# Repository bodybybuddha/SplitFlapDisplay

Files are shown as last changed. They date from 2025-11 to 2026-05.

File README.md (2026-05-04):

# Split-Flap Display

A modular, 3D-printed split-flap display controllable over RS485 from a Raspberry Pi. Each module holds 64 characters and modules can be chained together to build a display of any width.

**YouTube Build Video:** https://www.youtube.com/watch?v=-C8_AtxEEQc

---

## How It Works

Each module contains:
- A 3D-printed drum that holds 64 individual flaps (one per character)
- A stepper motor driving the drum through a gear train
- A Hall effect sensor for homing
- A custom driver PCB (ATtiny1616 + RS485 transceiver + ULN2003 stepper driver)

Modules communicate over a shared RS485 bus. A Raspberry Pi running a Python web interface sends commands over USB-RS485 to each module individually by address.

---

## Repository Structure

```
CAD/                              - 3D printable parts (Bambu Lab profiles included)
FlapsGenerator/                   - OpenSCAD code to automatically generate (custom) flaps
SplitFlapDriverATtiny1616 V2 KiCad/  - Driver PCB KiCad that I used in the video, for my build
SplitFlapDriverATtiny1616V3       - Updated Driver PCB KiCad project, which should be slightly cheaper to manufacture
SplitFlapBusBoard KiCad/          - Bus board KiCad project
SplitFlapFirmware/                - Arduino firmware for the PCBs
SplitFlap-RPI-FRONTEND/           - Raspberry Pi Python web frontend
Reference Docs/                   - Component datasheets
BOM.md                            - Bill of materials

**OnShape Model:** https://cad.onshape.com/documents/87c916b33ca5d6492b457485/w/b3e5f0f05f6619e6e7931347/e/582ef2164e20b0aa994708ab
```

---

## Parts List

See [BOM.md](BOM.md) for the complete bill of materials, broken into three sections:

- **PCB / Electronics** — all SMD components with JLCPCB part numbers for easy ordering
- **Module BOM** — 3D printed parts and hardware per module, with quantities scaled to 45 modules
- **Other Components** — system-level parts (Raspberry Pi, power supply, C14 connector, etc.)

---

## Ordering the PCB from JLCPCB

The driver board is designed to be ordered from JLCPCB with their PCB Assembly (PCBA) service so the SMD components arrive pre-soldered.

### Step 1 — Export Gerbers from KiCad

1. Open the project in `SplitFlapDriverATtiny1616 V2 KiCad/`
2. In KiCad PCB editor, go to **File → Fabrication Outputs → Gerbers**
3. Export to a folder, then zip the contents
4. Also export the drill file from the same menu

Alternatively, pre-exported Gerber and PCBA files are already be present in the KiCad project folder.

### Step 2 — Upload to JLCPCB

1. Go to [jlcpcb.com](https://jlcpcb.com) and click **Order Now**
2. Upload the Gerber zip file
3. Set your desired quantity (minimum 5)
4. Leave most settings at default; adjust PCB colour if desired

### Step 3 — Enable PCB Assembly (PCBA)

1. Toggle **PCB Assembly** on
2. Select **Standard PCBA** and set the assembly side to **Top Side**
3. Click **Confirm**

### Step 4 — Upload BOM and CPL Files

1. Upload the **BOM file** from the KiCad project folder — this maps component values to JLCPCB part numbers. The part numbers in `BOM.md` match what is in this file.
2. Upload the **CPL (Component Placement List)** file — this tells JLCPCB where each component sits on the board
3. Review the component matches on the next screen. All parts should auto-match using the C-numbers in [BOM.md](BOM.md). Confirm any that need manual review.

### Step 5 — Review and Order

1. Check the parts list — confirm quantities and part numbers match the [BOM.md](BOM.md) PCB section
2. Proceed through the review screens and place your order

> **Note:** A few through-hole parts (pin headers, JST connectors) are not included in PCBA. These are listed in the BOM and will need to be soldered by hand.

---

## 3D Printing

All printable files are in the `CAD/` folder. A Bambu Lab print profile is included in `CAD/64FlapsWithLetters/` for the flaps. Print the flaps in the correct colour for each character — see the video for details on the full 64-character set.

Parts per module:
- Enclosure Body, Right Cover, Left Cover
- Drum Body, Drum Cap
- Motor Gear, Center Gear, Gear Plate
- DIN Rail Mount, Wire Retainer
- 64 Flaps

### Creating your own flaps

If you want to generate your own flaps, with your own font, size and characters, you can use the OpenSCAD script to automatically generate this.

---

## Firmware

Located in `SplitFlapFirmware/`. The firmware is Arduino-based and targets the ATtiny1616.

- Flash via UPDI programmer (see https://github.com/SpenceKonde/AVR-Guidance/blob/master/UPDI/jtag2updi.md if you need to make one)
- Each module needs a unique address (0–44) stored in EEPROM. Be sure to edit this between flashes.

---

## Frontend

Located in `SplitFlap-RPI-FRONTEND/`. A Python web interface running on a Raspberry Pi sends display commands over USB-RS485 at 115200 baud.

Need a USB-serial dongle. I used this one: https://www.adafruit.com/product/5994

---

## License

This project is licensed under [Creative Commons Attribution-NonCommercial-ShareAlike 4.0 International (CC BY-NC-SA 4.0)](https://creativecommons.org/licenses/by-nc-sa/4.0/).

You are free to share and adapt this project for non-commercial purposes, as long as you give appropriate credit to Adam G Makes and distribute any derivatives under the same license.

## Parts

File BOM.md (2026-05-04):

# Split-Flap Display BOM (Bill of Materials)

## Project Overview
A modular split-flap display system with 64 characters per module, controllable via RS485 from a Raspberry Pi. Designed by Adam G Makes.

**YouTube Video:** https://www.youtube.com/watch?v=-C8_AtxEEQc

**YouTube Channel:** https://www.youtube.com/@AdamGMakes

---

## PCB / Electronics BOM (Per Driver Board)

| Comment | Designator | Footprint | JLCPCB Part # |
|---|---|---|---|
| ATtiny1616-MNR | U1 | VQFN-20-1EP_3x3mm_P0.4mm_EP1.7x1.7mm | C507118 |
| 470n | C3, C8, C6, C2 | C_0603_1608Metric | C1623 |
| ULN2003ADR | U2 | SOIC-16W_5.3x10.2mm_P1.27mm | C7512 |
| HallEffect | J4 | PinHeader_1x03_P2.54mm_Vertical | C131339 |
| 100u | C1 | C_Elec_5x5.4 | C3347 |
| 100n | C7 | C_0603_1608Metric | C14663 |
| **0R** | R1 | R_0805_2012Metric | C17477 |
| LED | D1 | LED_0201_0603Metric | C3646923 |
| StepperConnector | J3 | JST_XH_B5B-XH-A_1x05_P2.50mm_Vertical | C157991 |
| SN65HVD72DR | U3 | SOIC-8_5.3x6.2mm_P1.27mm | C48125 |
| 60R | R2 | R_0201_0603Metric | C88957 |
| SPX3819M5-L-3-3 | U5 | SOT-23-5 | C20617301 |
| SPX3819M5-L-5-0 | U6 | SOT-23-5 | C20617302 |
| 10u | C5, C9, C4 | C_0603_1608Metric | C19702 |

Note: R1 is a 0 Ohm resistor.
---

## Module BOM

### 3D Printed Parts

| Part | Qty per Module | Qty (45 Modules) |
|---|---|---|
| Enclosure Body | 1 | 45 |
| Enclosure Right Cover | 1 | 45 |
| Enclosure Left Cover | 1 | 45 |
| Drum Body | 1 | 45 |
| Drum Cap | 1 | 45 |
| DIN Rail Mount | 1 | 45 |
| Motor Gear | 1 | 45 |
| Center Gear | 1 | 45 |
| Gear Plate | 1 | 45 |
| Wire Retainer | 1 | 45 |
| Flap | 64 | 2880 |

### Other Parts

| Part | Qty per Module | Qty (45 Modules) |
|---|---|---|
| M3 Nuts | 12 | 540 |
| M3 x 8mm Flat Head Screw | 4 | 180 |
| M3 x 30mm Flat Head Screw | 4 | 180 |
| M3 x 40mm Flat Head Screw | 4 | 180 |
| A3144 Hall Effect Sensor | 1 | 45 |
| **28BYJ-48 12V Stepper Motor**| 1 | 45 |
| Driver Board | 1 | 45 |
| Pogo Pins *1 | 4 | 180 |
| 3x1mm N52 Magnet | 1 | 45 |
| 3-Pin JST Connector | 1 | 45 |

*1 -  Pogo Pin: total length 9mm needle head 2.0mm tube length 5.0mm tail length 2.0mm tail diameter 1.0mm (https://a.co/d/0a69mnW1)

Note: Keep in mind, the driver boards are designed to be used with 12V motors, not the common 5V variety.

---

## Other Components (System-Level)

| Qty | Component | Notes |
|-----|---|---|
| 1 | Raspberry Pi | Controller |
| 1 | USB-RS485 Dongle | PC/RPi to RS485 adapter |
| 1 | 12V Power Supply | Module power |
| 1 | C14 Power Connector | Panel-mount inlet |
| 1 | Power Switch | Main power switch |
| 1 | C14 Power Cable | IEC mains cable |

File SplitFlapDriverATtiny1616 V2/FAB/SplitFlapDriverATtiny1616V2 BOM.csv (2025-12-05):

Id | Designator | Footprint | Quantity | Designation | Supplier and ref
1 | U5 | SOT-23-5 | 1 | SPX3819M5-L-3-3
2 | C5,C9,C4 | C_0603_1608Metric | 3 | 10u
3 | C3,C8,C6,C2 | C_0603_1608Metric | 4 | 470n
4 | R1 | R_0805_2012Metric | 1 | 0R
5 | U6 | SOT-23-5 | 1 | SPX3819M5-L-5-0
6 | C7 | C_0603_1608Metric | 1 | 100n
7 | J4 | PinHeader_1x03_P2.54mm_Vertical | 1 | Hall Effect
8 | R2 | R_0201_0603Metric | 1 | 60R
9 | D1 | LED_0201_0603Metric | 1 | LED
10 | J8,J6,J2,J7 | PinHeader_1x01_P2.54mm_Vertical | 4 | Conn_01x01_Pin
11 | U2 | SOIC-16W_5.3x10.2mm_P1.27mm | 1 | ULN2003ADR
12 | U1 | VQFN-20-1EP_3x3mm_P0.4mm_EP1.7x1.7mm | 1 | ATtiny1616-MNR
13 | C1 | C_Elec_5x5.4 | 1 | 100u
14 | J3 | JST_XH_B5B-XH-A_1x05_P2.50mm_Vertical | 1 | Stepper Connector
15 | J1 | PinHeader_1x03_P2.54mm_Vertical | 1 | UPDI Programming
16 | U3 | SOIC-8_5.3x6.2mm_P1.27mm | 1 | SN65HVD72DR
17 | J5 | PinHeader_1x05_P2.54mm_Vertical | 1 | Conn_01x05_Pin

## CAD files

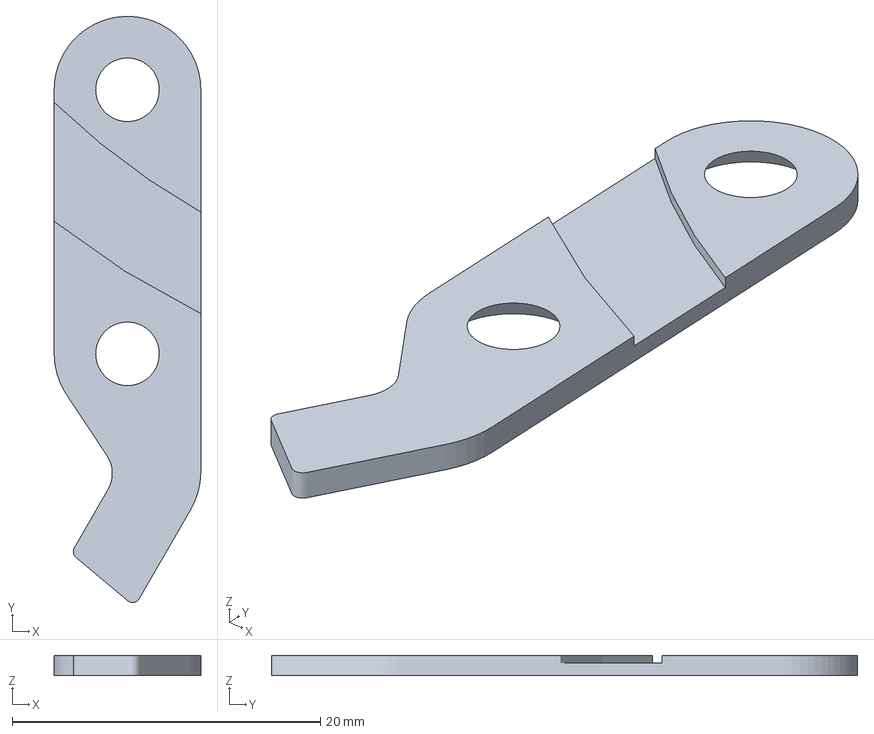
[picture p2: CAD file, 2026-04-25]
CAD/Wire Retainer.3mf
9.52 x 38.0 x 1.30 mm

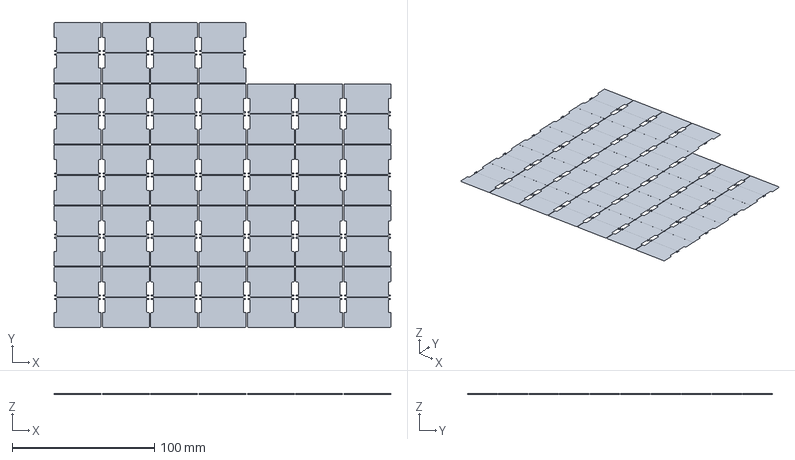
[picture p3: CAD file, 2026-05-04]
FlapsGenerator/examples/flaps_arial_28.3mf
237.1 x 214.3 x 0.48 mm

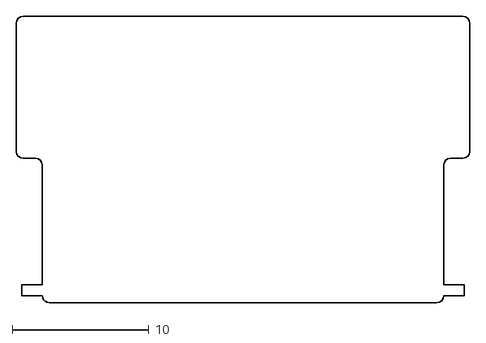
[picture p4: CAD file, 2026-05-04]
FlapsGenerator/flap.dxf
33.1 x 20.9

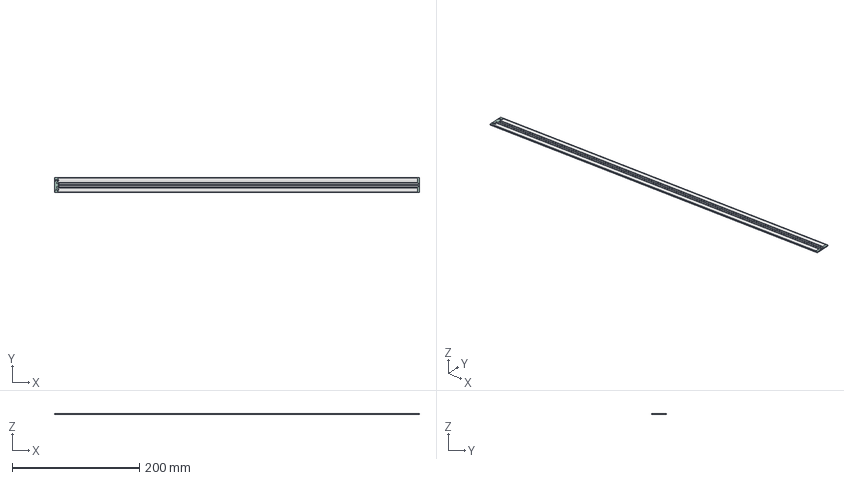
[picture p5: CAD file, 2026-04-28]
SplitFlapBusBoard 5-Module KiCad/SplitFlapBusBoard.step
572.6 x 24.0 x 1.62 mm
SplitFlapBusBoard_pad
SplitFlapBusBoard_silkscreen
SplitFlapBusBoard_PCB

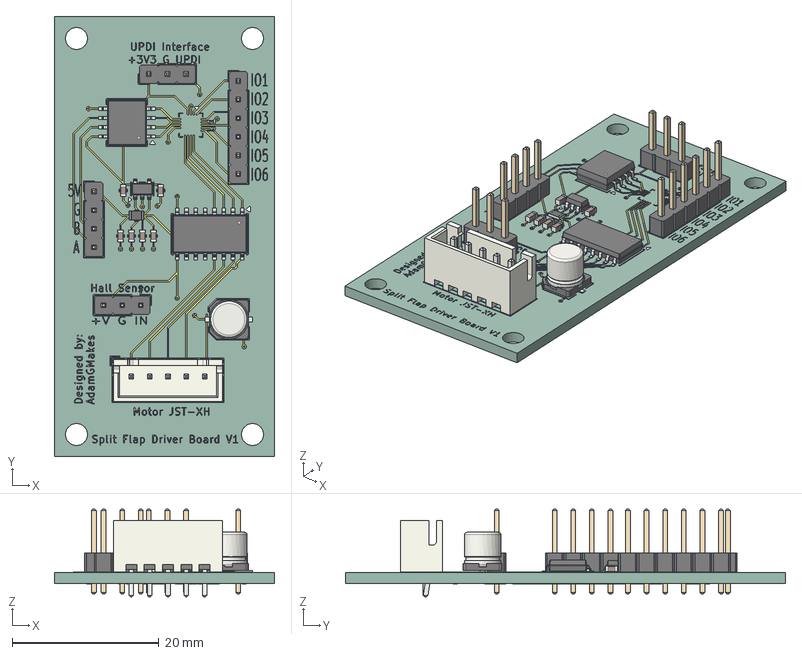
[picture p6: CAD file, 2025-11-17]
SplitFlapDriverATtiny1616 V2/SplitFlapDriverATtiny1616V2.step
30.0 x 60.0 x 11.9 mm
PinHeader_1x03_P2.54mm_Vertical x 2
C_0603_1608Metric x 6
SOIC-16W_5.3x10.2mm_P1.27mm
R_0805_2012Metric
C_Elec_5x5.4
PinHeader_1x04_P2.54mm_Vertical
JST_XH_B5B-XH-A_1x05_P2.50mm_Vertical
PinHeader_1x06_P2.54mm_Vertical
SOT-23-5
SOIC-8_5.3x6.2mm_P1.27mm
SplitFlapDriverATtiny1616V2_copper
SplitFlapDriverATtiny1616V2_via
SplitFlapDriverATtiny1616V2_silkscreen
SplitFlapDriverATtiny1616V2_PCB

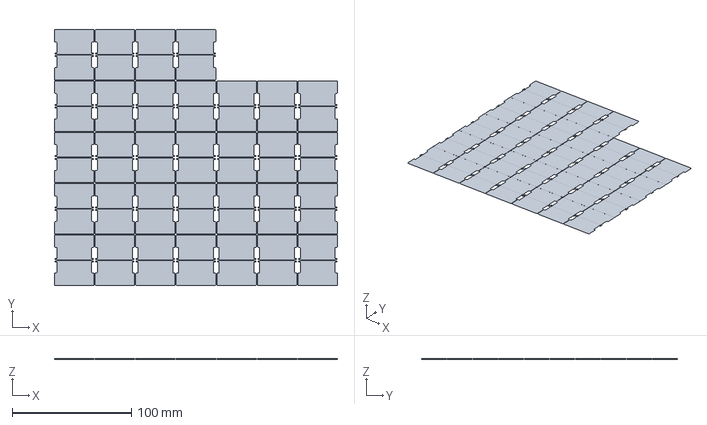
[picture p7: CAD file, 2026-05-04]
FlapsGenerator/examples/flaps_consolas_28.3mf
237.1 x 214.3 x 0.48 mm

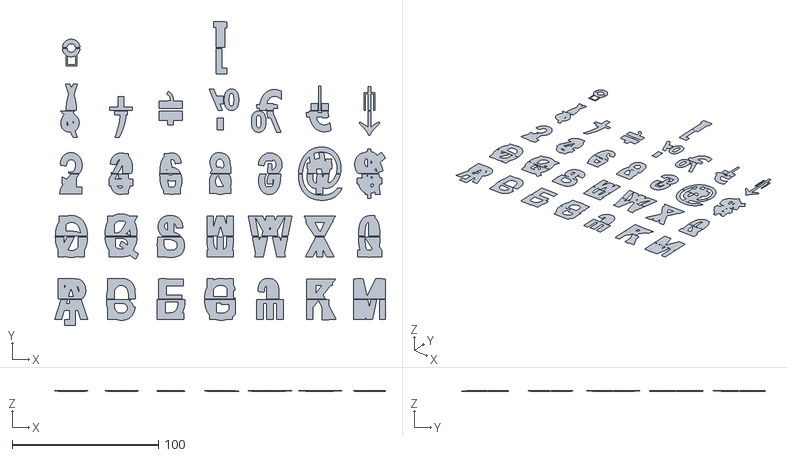
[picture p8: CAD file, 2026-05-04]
FlapsGenerator/examples/flaps_arial_28_inlay.stl
226.5 x 207.9 x 0.48

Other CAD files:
FlapsGenerator/flaps.scad

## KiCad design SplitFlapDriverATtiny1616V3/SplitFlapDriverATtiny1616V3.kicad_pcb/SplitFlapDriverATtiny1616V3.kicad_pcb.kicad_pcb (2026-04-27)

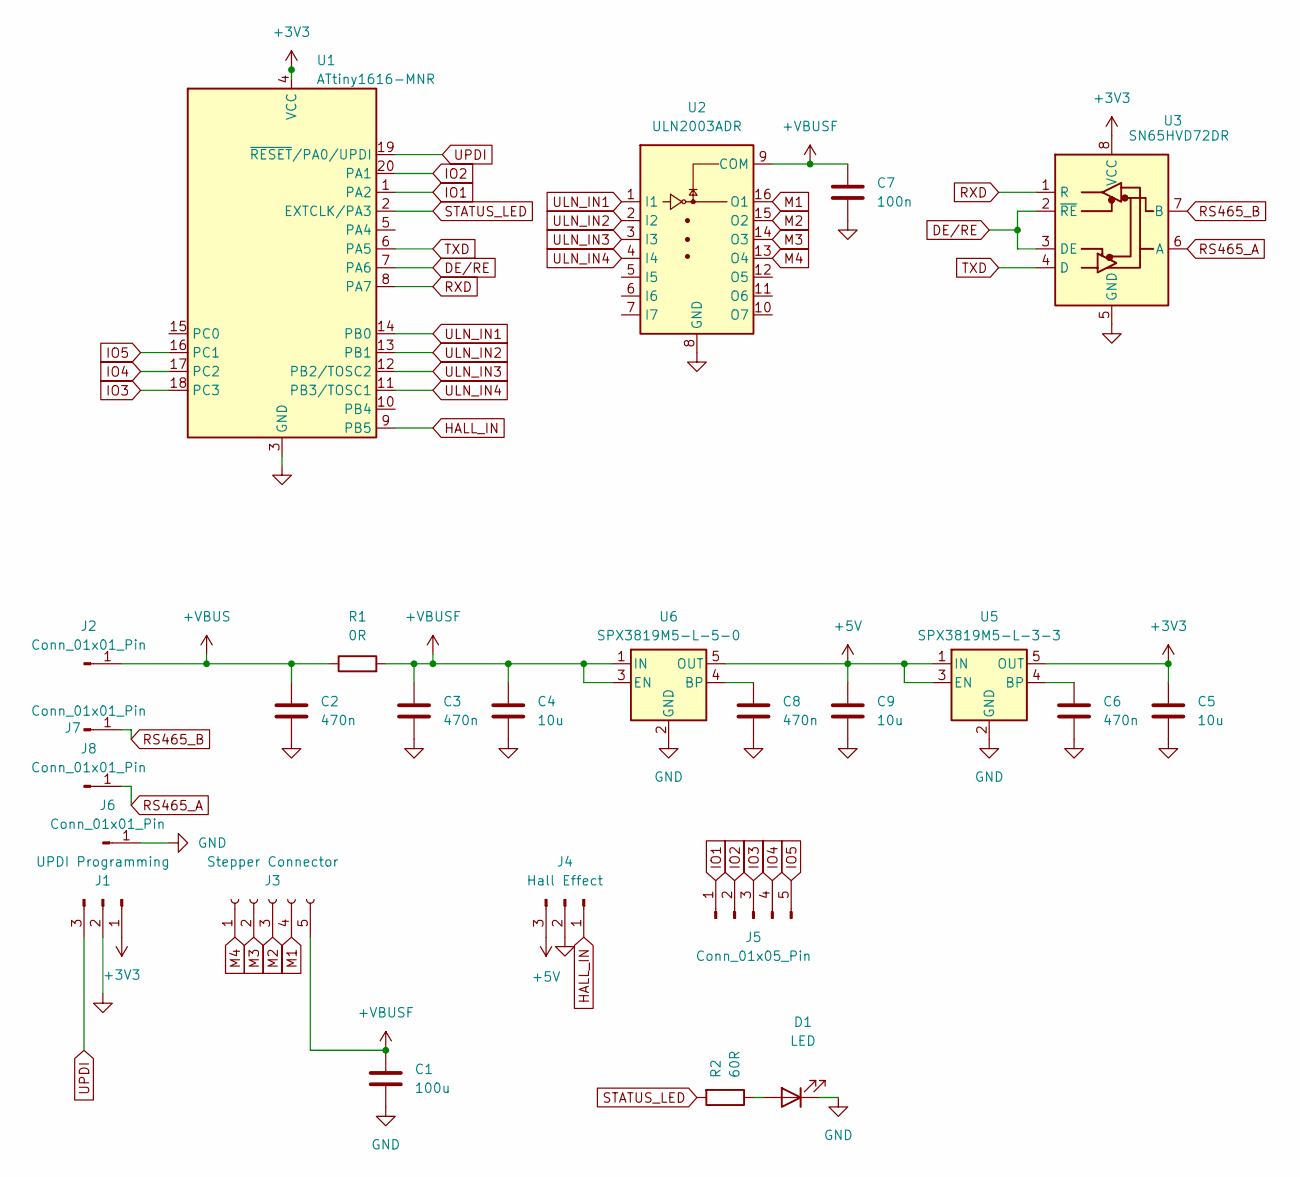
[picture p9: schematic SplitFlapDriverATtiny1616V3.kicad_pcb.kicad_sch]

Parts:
C1: 100u; C_Elec_5x5.4
C2, C3, C6, C8: 470n; C_0603_1608Metric
C4, C5, C9: 10u; C_0603_1608Metric
C7: 100n; C_0603_1608Metric
D1: LED; LED_0603_1608Metric
J1: UPDI Programming; PinHeader_1x03_P2.54mm_Vertical
J2, J6, J7, J8: Conn_01x01_Pin; PinHeader_1x01_P2.54mm_Vertical
J3: Stepper Connector; JST_XH_B5B-XH-A_1x05_P2.50mm_Vertical
J4: Hall Effect; JST_PH_B3B-PH-K_1x03_P2.00mm_Vertical
J5: Conn_01x05_Pin; PinHeader_1x05_P2.54mm_Vertical
R1: 0R; R_0805_2012Metric
R2: 60R; R_0603_1608Metric
U1: ATtiny1616-MNR; VQFN-20-1EP_3x3mm_P0.4mm_EP1.7x1.7mm; Manufacturer Part Number ATTINY1616-MNR; JLCPCB Part Number C507118
U2: ULN2003ADR; SOIC-16W_5.3x10.2mm_P1.27mm; Manufacturer Part Number ULN2003ADR; JLCPCB Part Number C7512
U3: SN65HVD72DR; SOIC-8_5.3x6.2mm_P1.27mm; Manufacturer Part Number SN65HVD72DR; JLCPCB Part Number C48125
U5: SPX3819M5-L-3-3; SOT-23-5
U6: SPX3819M5-L-5-0; SOT-23-5

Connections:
+3V3: C5.1, J1.1, U1.4 (VCC), U3.8 (VCC), U5.5 (OUT)
+5V: C9.1, J4.3, U5.1 (IN), U5.3 (EN), U6.5 (OUT)
+VBUS: C2.1, J2.1, R1.1
+VBUSF: C1.1, C3.1, C4.1, C7.1, J3.5, R1.2, U2.9 (COM), U6.1 (IN), U6.3 (EN)
DE/RE: U1.7 (PA6), U3.2 (~RE), U3.3 (DE)
GND: C1.2, C2.2, C3.2, C4.2, C5.2, C6.2, C7.2, C8.2, C9.2, D1.1 (K), J1.2, J4.2, J6.1, U1.3 (GND), U2.8 (GND), U3.5 (GND), U5.2 (GND), U6.2 (GND)
HALL_IN: J4.1, U1.9 (PB5)
IO1: J5.1, U1.1 (PA2)
IO2: J5.2, U1.20 (PA1)
IO3: J5.3, U1.18 (PC3)
IO4: J5.4, U1.17 (PC2)
IO5: J5.5, U1.16 (PC1)
M1: J3.4, U2.16 (O1)
M2: J3.3, U2.15 (O2)
M3: J3.2, U2.14 (O3)
M4: J3.1, U2.13 (O4)
unnamed: D1.2 (A), R2.1
unnamed: C6.1, U5.4 (BP)
unnamed: C8.1, U6.4 (BP)
RS465_A: J8.1, U3.6 (A)
RS465_B: J7.1, U3.7 (B)
RXD: U1.8 (PA7), U3.1 (R)
STATUS_LED: R2.2, U1.2 (EXTCLK/PA3)
TXD: U1.6 (PA5), U3.4 (D)
ULN_IN1: U1.14 (PB0), U2.1 (I1)
ULN_IN2: U1.13 (PB1), U2.2 (I2)
ULN_IN3: U1.12 (PB2/TOSC2), U2.3 (I3)
ULN_IN4: U1.11 (PB3/TOSC1), U2.4 (I4)
UPDI: J1.3, U1.19 (~RESET/PA0/UPDI)

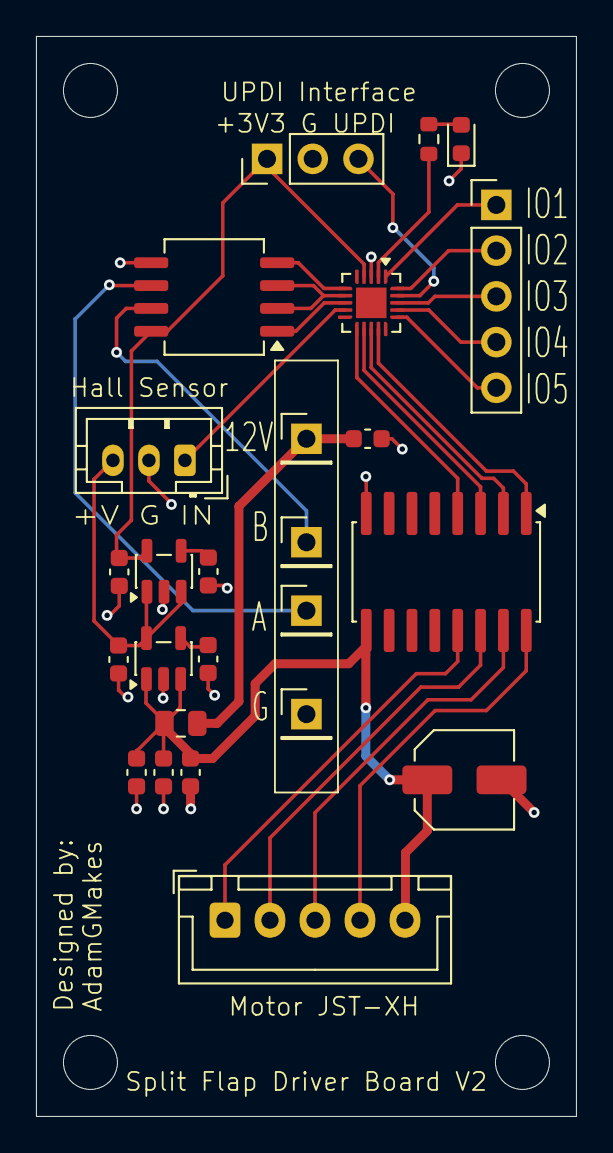
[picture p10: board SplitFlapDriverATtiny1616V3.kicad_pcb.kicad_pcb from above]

Board: 2 copper layers, 30.0 x 60.0 mm, 25 parts (0 on the bottom side), 29 nets.

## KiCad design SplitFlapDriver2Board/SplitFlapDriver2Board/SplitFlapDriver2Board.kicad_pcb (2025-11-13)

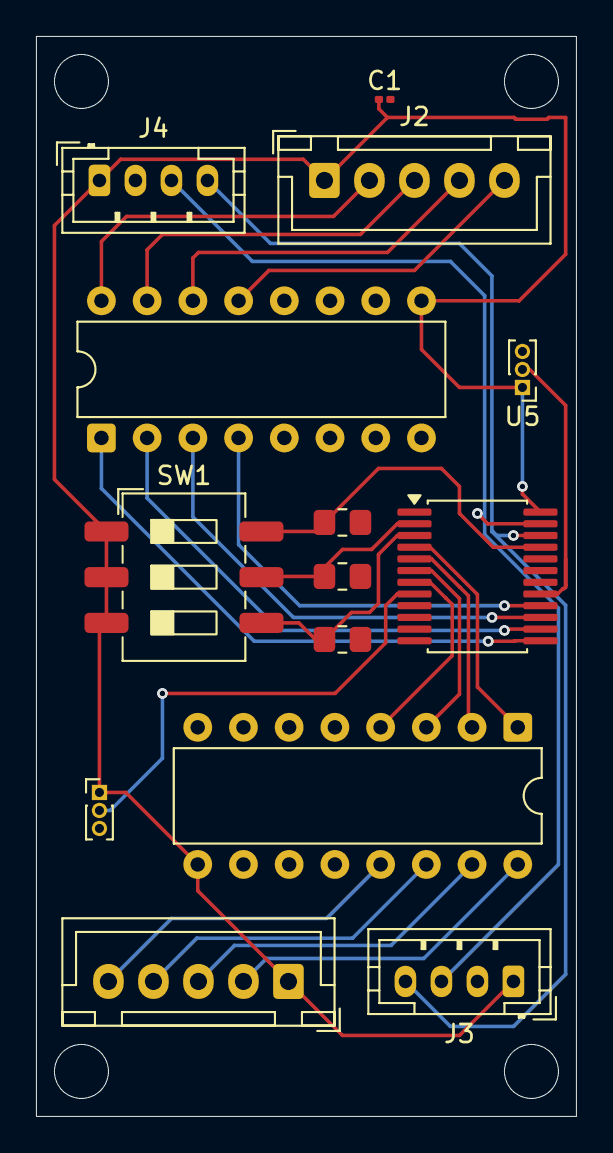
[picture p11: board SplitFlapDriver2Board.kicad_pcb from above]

Board: 2 copper layers, 30.0 x 60.0 mm, 14 parts (0 on the bottom side), 25 nets.

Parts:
C1: C_Polarized; C_0201_0603Metric
J1, J2: Conn_01x05_Socket; JST_XH_B5B-XH-A_1x05_P2.50mm_Vertical
J3: Conn_01x04_Socket; JST_PH_B4B-PH-K_1x04_P2.00mm_Vertical
J4: Conn_01x04_Pin; JST_PH_B4B-PH-K_1x04_P2.00mm_Vertical
R1, R2, R3: 9.1K; R_0805_2012Metric_Pad1.20x1.40mm_HandSolder
SW1: SW_DIP_x03; SW_DIP_SPSTx03_Slide_6.7x9.18mm_W8.61mm_P2.54mm_LowProfile
U1: PCF8575DBR; SSOP-24_5.3x8.2mm_P0.65mm
U2, U3: ULN2003A; DIP-16_W7.62mm
U4, U5: A1104xLH; PinHeader_1x03_P1.00mm_Vertical

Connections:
+5V: C1.1, J1.1, J2.1, J3.1, J4.1, SW1.1, SW1.2, SW1.3, U1.24 (VCC), U2.9 (COM), U3.9 (COM), U4.1 (V_{CC}), U5.1 (V_{CC})
GND: C1.2, J3.2, J4.2, R1.2, R2.2, R3.2, U1.12 (GND), U2.8 (GND), U3.8 (GND), U4.3 (GND), U5.3 (GND)
unnamed: J1.2, U2.16 (O1)
unnamed: J1.3, U2.15 (O2)
unnamed: J1.4, U2.14 (O3)
unnamed: J1.5, U2.13 (O4)
unnamed: J2.2, U3.16 (O1)
unnamed: J2.3, U3.15 (O2)
unnamed: J2.4, U3.14 (O3)
unnamed: J2.5, U3.13 (O4)
unnamed: R3.1, SW1.6, U1.21 (A0)
unnamed: R2.1, SW1.5, U1.2 (A1)
unnamed: R1.1, SW1.4, U1.3 (A2)
unnamed: U1.4 (P0), U2.1 (I1)
unnamed: U1.5 (P1), U2.2 (I2)
unnamed: U1.6 (P2), U2.3 (I3)
unnamed: U1.7 (P3), U2.4 (I4)
unnamed: U1.8 (P4), U4.2 (V_{OUT})
unnamed: U1.13 (P10), U3.1 (I1)
unnamed: U1.14 (P11), U3.2 (I2)
unnamed: U1.15 (P12), U3.3 (I3)
unnamed: U1.16 (P13), U3.4 (I4)
unnamed: U1.17 (P14), U5.2 (V_{OUT})
SCL: J3.4, J4.4, U1.22 (SCL)
SDA: J3.3, J4.3, U1.23 (SDA)

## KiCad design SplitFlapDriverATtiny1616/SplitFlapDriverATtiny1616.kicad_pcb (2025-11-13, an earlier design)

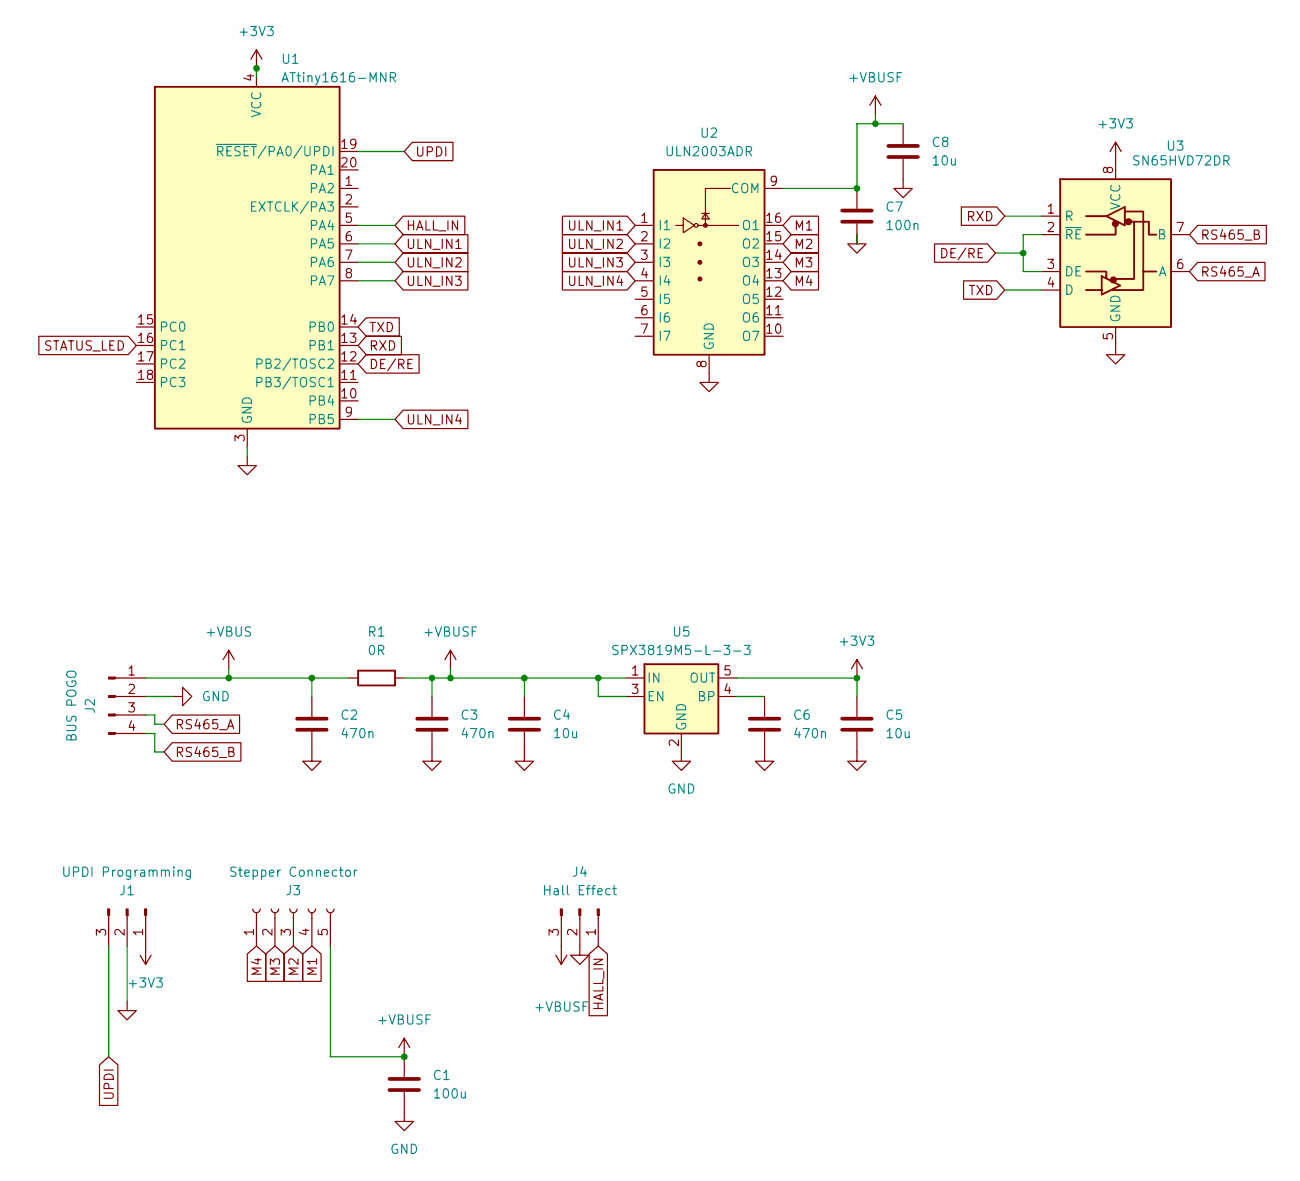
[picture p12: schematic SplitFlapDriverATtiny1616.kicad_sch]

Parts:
C1: 100u; C_Elec_5x5.4
C2, C3, C6: 470n; C_0603_1608Metric
C4, C5, C8: 10u; C_0603_1608Metric
C7: 100n; C_0603_1608Metric
J1: UPDI Programming; PinHeader_1x03_P2.54mm_Vertical
J2: BUS POGO; PinHeader_1x04_P2.54mm_Vertical
J3: Stepper Connector; JST_XH_B5B-XH-A_1x05_P2.50mm_Vertical
J4: Hall Effect; PinHeader_1x03_P2.54mm_Vertical
R1: 0R; R_0805_2012Metric
U1: ATtiny1616-MNR; VQFN-20-1EP_3x3mm_P0.4mm_EP1.7x1.7mm; Manufacturer Part Number ATTINY1616-MNR; JLCPCB Part Number C507118
U2: ULN2003ADR; SOIC-16W_5.3x10.2mm_P1.27mm; Manufacturer Part Number ULN2003ADR; JLCPCB Part Number C7512
U3: SN65HVD72DR; SOIC-8_5.3x6.2mm_P1.27mm; Manufacturer Part Number SN65HVD72DR; JLCPCB Part Number C48125
U5: SPX3819M5-L-3-3; SOT-23-5

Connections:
+3V3: C5.1, J1.1, U1.4 (VCC), U3.8 (VCC), U5.5 (OUT)
+VBUS: C2.1, J2.1, R1.1
+VBUSF: C1.1, C3.1, C4.1, C7.1, C8.1, J3.5, J4.3, R1.2, U2.9 (COM), U5.1 (IN), U5.3 (EN)
DE/RE: U1.12 (PB2/TOSC2), U3.2 (~RE), U3.3 (DE)
GND: C1.2, C2.2, C3.2, C4.2, C5.2, C6.2, C7.2, C8.2, J1.2, J2.2, J4.2, U1.3 (GND), U2.8 (GND), U3.5 (GND), U5.2 (GND)
HALL_IN: J4.1, U1.5 (PA4)
M1: J3.4, U2.16 (O1)
M2: J3.3, U2.15 (O2)
M3: J3.2, U2.14 (O3)
M4: J3.1, U2.13 (O4)
unnamed: C6.1, U5.4 (BP)
RS465_A: J2.3, U3.6 (A)
RS465_B: J2.4, U3.7 (B)
RXD: U1.13 (PB1), U3.1 (R)
STATUS_LED: U1.16 (PC1)
TXD: U1.14 (PB0), U3.4 (D)
ULN_IN1: U1.6 (PA5), U2.1 (I1)
ULN_IN2: U1.7 (PA6), U2.2 (I2)
ULN_IN3: U1.8 (PA7), U2.3 (I3)
ULN_IN4: U1.9 (PB5), U2.4 (I4)
UPDI: J1.3, U1.19 (~RESET/PA0/UPDI)

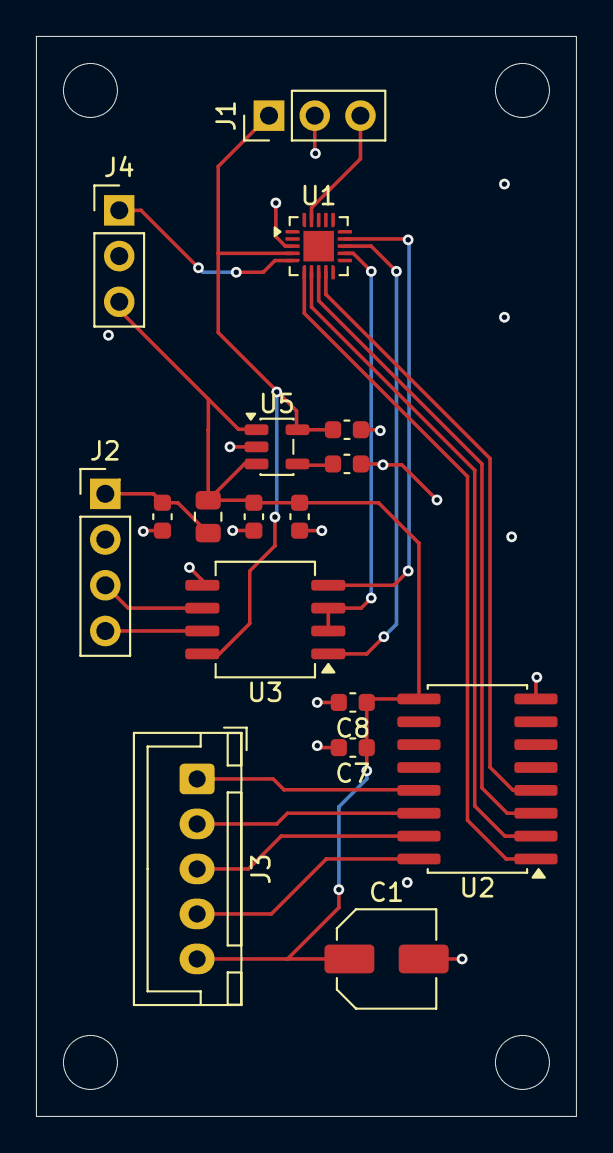
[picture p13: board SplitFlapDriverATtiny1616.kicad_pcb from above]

Board: 2 copper layers, 30.0 x 60.0 mm, 17 parts (0 on the bottom side), 20 nets.

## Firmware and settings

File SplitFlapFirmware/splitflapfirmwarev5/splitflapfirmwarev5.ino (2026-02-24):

#include <SoftwareSerial.h>
#include <EEPROM.h>

// ==========================================
//               CONFIGURATION
// ==========================================
// !!! CHANGE THIS FOR EACH MODULE TODAY !!!
const uint8_t HARDCODED_ID = 11; 

const String FLAP_CHARS = " ABCDEFGHIJKLMNOPQRSTUVWXYZ0123456789!@#$&()-+=;q:%'.,/?*roygbpw";

// EEPROM MAP
const int ADDR_INIT = 0;          // 1 byte  - Initialization flag
const int ADDR_HOME_OFFSET = 1;   // 2 bytes - Offset from magnet
const int ADDR_TOTAL_STEPS = 3;   // 2 bytes - Step length of reel
const int ADDR_MODULE_ID = 5;     // 1 byte  - The Module's Assigned ID (0-44)
const int ADDR_AUTO_HOME = 6;     // 1 byte  - Toggle for booting logic
const int ADDR_SAVED_POS = 7;     // 2 bytes - Last known step position
const int ADDR_SAVED_INDEX = 9;   // 1 byte  - Last known character index
const int ADDR_MAP_START = 12;    // 128 bytes - Exact character positions
const uint8_t INIT_VALUE = 0x5D;  // Magic number updated for new map

// Operating Variables
uint8_t moduleId = 255;
char idChars[2] = {'*', '*'};
bool autoHomeEnabled = true;

int stepsFromHallToZero = 2832;
int totalStepsPerRev = 4096;

// ==========================================
//              PIN DEFINITIONS
// ==========================================
const int RS485_RX = 3;
const int RS485_TX = 1;
const int RS485_DE = 2;

#define IN1 9
#define IN2 8
#define IN3 7
#define IN4 6
#define HALL_PIN 4

// ==========================================
//               GLOBALS
// ==========================================
SoftwareSerial rs485(RS485_RX, RS485_TX);

long currentStepPos = 0; 
int currentPhase = 0;
int parseState = 0; 
int currentFlapIndex = -1;
int tempIndex = -1;

const int stepDelay = 1;
String buffer = "";
unsigned long lastSerialTime = 0;

const uint8_t halfStepSequence[8][4] = {
  {1, 0, 0, 0}, {1, 1, 0, 0}, {0, 1, 0, 0}, {0, 1, 1, 0},
  {0, 0, 1, 0}, {0, 0, 1, 1}, {0, 0, 0, 1}, {1, 0, 0, 1}
};

// ==========================================
//             EEPROM FUNCTIONS
// ==========================================

void saveHomeOffset() { EEPROM.put(ADDR_HOME_OFFSET, stepsFromHallToZero); }
void saveTotalSteps() { EEPROM.put(ADDR_TOTAL_STEPS, totalStepsPerRev); }

void saveState() {
  // THE COMPROMISE: Only wear out the EEPROM if Auto-Home is explicitly DISABLED
  if (!autoHomeEnabled) {
    EEPROM.put(ADDR_SAVED_POS, currentStepPos);
    EEPROM.put(ADDR_SAVED_INDEX, currentFlapIndex);
  }
}

void updateIdChars() {
  if(moduleId < 100) {
    idChars[0] = (moduleId / 10) + '0';
    idChars[1] = (moduleId % 10) + '0';
  }
}

// ==========================================
//             MOTOR FUNCTIONS
// ==========================================

void applyStep(const uint8_t *step) {
  digitalWrite(IN1, step[0]);
  digitalWrite(IN2, step[1]);
  digitalWrite(IN3, step[2]); 
  digitalWrite(IN4, step[3]);
}

void stepBackward(int steps) {
  for (int k = 0; k < steps; k++) {
    bool hallNow = hallActive();
    static bool lastHallState = false;

    if (hallNow && !lastHallState) {
      currentStepPos = totalStepsPerRev - stepsFromHallToZero;
    }
    lastHallState = hallNow;

    currentPhase--;
    if (currentPhase < 0) {
      currentPhase = 7;
    }
    
    applyStep(halfStepSequence[currentPhase]);
    delay(stepDelay);
    
    currentStepPos++;
    if (currentStepPos >= totalStepsPerRev) {
      currentStepPos = 0;
    }
  }
}

void releaseMotor() {
  digitalWrite(IN1,0); digitalWrite(IN2,0); digitalWrite(IN3,0); digitalWrite(IN4,0);
}

bool hallActive() {
  return (digitalRead(HALL_PIN) == LOW);
}

// ==========================================
//             LOGIC FUNCTIONS
// ==========================================

void homeModule() {
  long safety = 0;
  while (!hallActive() && safety < (totalStepsPerRev + 500)) {
    stepBackward(1);
    safety++;
  }
  
  stepBackward(stepsFromHallToZero);
  currentStepPos = 0; 
  currentFlapIndex = 0;
  releaseMotor();
}

void calibrateModule() {
  long safety = 0;
  while (hallActive() && safety < 4000) {
    stepBackward(1);
    safety++;
    delay(5);
  }

  safety = 0;
  while (!hallActive() && safety < 5000) {
    stepBackward(1);
    safety++;
  }

  while (hallActive()) {
    stepBackward(1);
  }

  int measuredSteps = 0;
  while (!hallActive() && measuredSteps < 5000) {
    stepBackward(1);
    measuredSteps++;
  }

  while (hallActive()) {
    stepBackward(1);
    measuredSteps++;
  }

  digitalWrite(RS485_DE, HIGH);
  delay(5); 
  
  rs485.print("m");
  if(moduleId < 100) {
    rs485.print(idChars[0]);
    rs485.print(idChars[1]);
  } else {
    rs485.print("XX");
  }
  rs485.print(":");
  rs485.println(measuredSteps);
  
  rs485.flush(); 
  delay(5);
  digitalWrite(RS485_DE, LOW);
  
  totalStepsPerRev = measuredSteps;
  saveTotalSteps();
  homeModule();
  saveState();
}

void moveToChar(char targetChar) {
  int targetIndex = FLAP_CHARS.indexOf(targetChar);
  if (targetIndex == -1) return;
  if (currentFlapIndex == targetIndex) return; 
  
  if (currentFlapIndex == -1) {
    homeModule();
  }

  uint16_t mappedPos = 0xFFFF;
  EEPROM.get(ADDR_MAP_START + (targetIndex * 2), mappedPos);
  
  long targetStepPos;
  if (mappedPos != 0xFFFF) {
    targetStepPos = mappedPos;
  } else {
    targetStepPos = ((long)targetIndex * (long)totalStepsPerRev) / 64;
  }
  
  long stepsToMove = targetStepPos - currentStepPos;
  if (stepsToMove < 0) {
    stepsToMove += totalStepsPerRev;
  }
  
  while(stepsToMove > 0) {
    stepBackward(1);
    stepsToMove--;
  }

  releaseMotor();
  currentFlapIndex = targetIndex; 
  saveState(); 
}

// ==========================================
//              MAIN LOOP
// ==========================================

void setup() {
  pinMode(IN1, OUTPUT);
  pinMode(IN2, OUTPUT);
  pinMode(IN3, OUTPUT); 
  pinMode(IN4, OUTPUT);
  pinMode(HALL_PIN, INPUT_PULLUP);
  
  pinMode(RS485_DE, OUTPUT);
  digitalWrite(RS485_DE, LOW); 
  
  if (EEPROM.read(ADDR_INIT) == INIT_VALUE) {
    EEPROM.get(ADDR_HOME_OFFSET, stepsFromHallToZero);
    EEPROM.get(ADDR_TOTAL_STEPS, totalStepsPerRev);
    moduleId = EEPROM.read(ADDR_MODULE_ID);
    autoHomeEnabled = (EEPROM.read(ADDR_AUTO_HOME) == 1);
  } else {
    EEPROM.write(ADDR_INIT, INIT_VALUE);
    saveHomeOffset();
    saveTotalSteps();
    
    moduleId = HARDCODED_ID; 
    EEPROM.write(ADDR_MODULE_ID, moduleId);
    
    EEPROM.write(ADDR_AUTO_HOME, 1);
    autoHomeEnabled = true;
    
    for(int i=0; i<64; i++) {
      uint16_t empty = 0xFFFF;
      EEPROM.put(ADDR_MAP_START + (i*2), empty);
    }
  }

  updateIdChars();
  rs485.begin(9600);

  if (moduleId != 255) {
    delay(moduleId * 150); 
  }
  
  if (autoHomeEnabled) {
    homeModule();
    saveState(); // Will safely do nothing because autoHomeEnabled is true
  } else {
    // Restore state from memory
    EEPROM.get(ADDR_SAVED_POS, currentStepPos);
    
    // Safety check in case memory is corrupted or uninitialized
    if (currentStepPos >= totalStepsPerRev) currentStepPos = 0;
    
    currentFlapIndex = (int8_t)EEPROM.read(ADDR_SAVED_INDEX);
  }
}

void loop() {
  while (rs485.available()) {
    char c = rs485.read();
    lastSerialTime = millis();
    
    switch (parseState) {
      case 0: if (c == 'm') parseState = 1; break;
      case 1: if (c == idChars[0] || c == '*') parseState = 2; else parseState = 0; break;
      case 2: if (c == idChars[1] || c == '*') parseState = 3; else parseState = 0; break;
      
      case 3: 
        if (c == '-') parseState = 4;
        else if (c == 'h') { homeModule(); saveState(); parseState = 0; }
        else if (c == 'c') { calibrateModule(); parseState = 0; }
        else if (c == 'o') { buffer = ""; parseState = 5; }
        else if (c == 't') { buffer = ""; parseState = 6; }
        else if (c == 's') { buffer = ""; parseState = 7; } 
        else if (c == 'g') { buffer = ""; parseState = 8; } 
        else if (c == 'w') { buffer = ""; tempIndex = -1; parseState = 9; } 
        else if (c == 'i') { buffer = ""; parseState = 10; } 
        else if (c == 'a') { buffer = ""; parseState = 11; } 
        else if (c == 'e') { 
          for(int i=0; i<64; i++) {
            uint16_t empty = 0xFFFF;
            EEPROM.put(ADDR_MAP_START + (i*2), empty);
          }
          parseState = 0;
        } 
        else parseState = 0;
        break;
        
      case 4: moveToChar(c); parseState = 0; break;
      
      case 5: 
        if (isDigit(c)) buffer += c;
        else { 
          if (buffer.length()>0) {
            stepsFromHallToZero = buffer.toInt(); 
            saveHomeOffset();
          }
          parseState=0; 
        }
        break;
        
      case 6: 
        if (isDigit(c)) buffer += c;
        else { 
          if (buffer.length()>0) {
            totalStepsPerRev = buffer.toInt(); 
            saveTotalSteps();
          }
          parseState=0; 
        }
        break;
        
      case 7: 
        if (isDigit(c)) buffer += c;
        else { 
          if (buffer.length()>0) {
            int stepsToMove = buffer.toInt();
            stepBackward(stepsToMove);
            releaseMotor();
            stepsFromHallToZero += stepsToMove;
            saveHomeOffset();
          }
          parseState=0; 
        }
        break;
        
      case 8: 
        if (isDigit(c)) buffer += c;
        else {
          if (buffer.length() > 0) {
            long targetStep = buffer.toInt();
            long stepsToMove = targetStep - currentStepPos;
            if (stepsToMove < 0) stepsToMove += totalStepsPerRev;
            while(stepsToMove > 0) { stepBackward(1); stepsToMove--; }
            releaseMotor();
            currentFlapIndex = -2;
            saveState(); 
          }
          parseState = 0;
        }
        break;
        
      case 9: 
        if (c == ':') {
          tempIndex = buffer.toInt();
          buffer = "";
        } else if (isDigit(c)) {
          buffer += c;
        } else {
          if (buffer.length() > 0 && tempIndex != -1) {
            uint16_t pos = buffer.toInt();
            EEPROM.put(ADDR_MAP_START + (tempIndex * 2), pos);
          }
          parseState = 0;
        }
        break;

      case 10: 
        if (isDigit(c)) buffer += c;
        else {
          if (buffer.length() > 0) {
            moduleId = buffer.toInt();
            EEPROM.write(ADDR_MODULE_ID, moduleId);
            updateIdChars();
          }
          parseState = 0;
        }
        break;

      case 11: 
        if (isDigit(c)) buffer += c;
        else {
          if (buffer.length() > 0) {
            autoHomeEnabled = (buffer.toInt() == 1);
            EEPROM.write(ADDR_AUTO_HOME, autoHomeEnabled ? 1 : 0);
            saveState(); // Instantly save current resting state if we just turned Auto-Home OFF
          }
          parseState = 0;
        }
        break;
    }
  }

  // Timeouts for number parsing
  if ((parseState >= 5 && parseState <= 11) && (millis() - lastSerialTime > 50)) {
    if (buffer.length() > 0) {
      if (parseState == 5) { stepsFromHallToZero = buffer.toInt(); saveHomeOffset(); }
      if (parseState == 6) { totalStepsPerRev = buffer.toInt(); saveTotalSteps(); }
      if (parseState == 7) {
        int stepsToMove = buffer.toInt();
        stepBackward(stepsToMove);
        releaseMotor();
        stepsFromHallToZero += stepsToMove;
        saveHomeOffset();
      }
      if (parseState == 8) {
        long targetStep = buffer.toInt();
        long stepsToMove = targetStep - currentStepPos;
        if (stepsToMove < 0) stepsToMove += totalStepsPerRev;
        while(stepsToMove > 0) { stepBackward(1); stepsToMove--; }
        releaseMotor();
        currentFlapIndex = -2;
        saveState();
      }
      if (parseState == 9 && tempIndex != -1) {
        uint16_t pos = buffer.toInt();
        EEPROM.put(ADDR_MAP_START + (tempIndex * 2), pos);
      }
      if (parseState == 10) {
        moduleId = buffer.toInt();
        EEPROM.write(ADDR_MODULE_ID, moduleId);
        updateIdChars();
      }
      if (parseState == 11) {
        autoHomeEnabled = (buffer.toInt() == 1);
        EEPROM.write(ADDR_AUTO_HOME, autoHomeEnabled ? 1 : 0);
        saveState();
      }
    }
    parseState = 0;
  }
}

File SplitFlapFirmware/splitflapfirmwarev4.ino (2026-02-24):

#include <SoftwareSerial.h>

// ==========================================
//               CONFIGURATION
// ==========================================
// !!! CHANGE THIS FOR EACH MODULE !!!
const String MODULE_ID = "m44"; 

const String FLAP_CHARS = " ABCDEFGHIJKLMNOPQRSTUVWXYZ0123456789!@#$&()-+=;q:%'.,/?*roygbpw";

// Hardware Settings
// TUNABLE VARIABLES (Can be updated via RS485)
// Note: These are now in HALF-STEPS. 
// Old value 354 * 8 = 2832
int stepsFromHallToZero = 2832; 
// Old value 512 * 8 = 4096 half-steps per revolution
int totalStepsPerRev = 4096; 

// ==========================================
//              PIN DEFINITIONS
// ==========================================
const int RS485_RX = 3;
const int RS485_TX = 1;
const int RS485_DE = 2;

#define IN1 9
#define IN2 8
#define IN3 7
#define IN4 6
#define HALL_PIN 4

// ==========================================
//               GLOBALS
// ==========================================
SoftwareSerial rs485(RS485_RX, RS485_TX);

long currentStepPos = 0; // Absolute position in half-steps from the sensor trigger
int currentPhase = 0;    // Tracks the current electrical phase (0-7)

int parseState = 0; 
int currentFlapIndex = -1;

const int stepDelay = 1; 
String buffer = "";
unsigned long lastSerialTime = 0;

const uint8_t halfStepSequence[8][4] = {
  {1, 0, 0, 0}, {1, 1, 0, 0}, {0, 1, 0, 0}, {0, 1, 1, 0},
  {0, 0, 1, 0}, {0, 0, 1, 1}, {0, 0, 0, 1}, {1, 0, 0, 1}
};

// ==========================================
//             MOTOR FUNCTIONS
// ==========================================

void applyStep(const uint8_t *step) {
  digitalWrite(IN1, step[0]);
  digitalWrite(IN2, step[1]);
  digitalWrite(IN3, step[2]); 
  digitalWrite(IN4, step[3]);
}

void stepBackward(int steps) {
  for (int k = 0; k < steps; k++) {
    // 1. Check for drift correction (Falling Edge Detection)
    bool hallNow = hallActive();
    static bool lastHallState = false;

    // If Hall sensor just went from HIGH to LOW (Magnet just arrived)
    if (hallNow && !lastHallState) {
      // Self-Healing moment
      currentStepPos = totalStepsPerRev - stepsFromHallToZero;
    }
    lastHallState = hallNow;

    // 2. Perform ONE phase of the half-step sequence
    currentPhase--;
    if (currentPhase < 0) {
      currentPhase = 7; // Wrap around to keep the backward rotation
    }
    
    applyStep(halfStepSequence[currentPhase]);
    delay(stepDelay);
    
    // 3. Increment our internal counter (now counting half-steps)
    currentStepPos++;
    
    // 4. Wrap around if we exceed the calibrated total
    if (currentStepPos >= totalStepsPerRev) {
      currentStepPos = 0;
    }
  }
}

void releaseMotor() {
  digitalWrite(IN1,0); digitalWrite(IN2,0); digitalWrite(IN3,0); digitalWrite(IN4,0);
}

bool hallActive() {
  return (digitalRead(HALL_PIN) == LOW); // LOW = Magnet Detected
}

// ==========================================
//             LOGIC FUNCTIONS
// ==========================================

void homeModule() {
  long safety = 0;
  
  // 1. Find magnet (Increased safety limit for half-steps)
  while (!hallActive() && safety < (totalStepsPerRev + 500)) {
    stepBackward(1);
    safety++;
  }
  
  // 2. We are exactly at the trigger point (0)
  
  // 3. Move to Space
  stepBackward(stepsFromHallToZero);
  currentStepPos = 0; // currentStepPos is now automatically 0
  
  currentFlapIndex = 0;
  releaseMotor();
}

void calibrateModule() {
  // 1. First, make sure we are NOT on the magnet.
  long safety = 0;
  while (hallActive() && safety < 4000) {
    stepBackward(1);
    safety++;
    delay(5); // Slow down for accuracy
  }

  // 2. Now spin until we HIT the magnet (Falling Edge)
  safety = 0;
  while (!hallActive() && safety < 5000) {
    stepBackward(1);
    safety++;
  }

  // 3. We just hit the magnet. Now move until we LEAVE the magnet.
  while (hallActive()) {
    stepBackward(1);
  }

  // 4. START COUNTING
  int measuredSteps = 0;
  
  // 5. Spin until we hit the magnet again
  while (!hallActive() && measuredSteps < 5000) {
    stepBackward(1);
    measuredSteps++;
  }

  // 6. Spin until we leave the magnet again (Full Circle Completed)
  while (hallActive()) {
    stepBackward(1);
    measuredSteps++;
  }

  // 7. BROADCAST DATA
  digitalWrite(RS485_DE, HIGH);
  delay(5); 
  
  rs485.print("m");
  rs485.print(MODULE_ID.substring(1));
  rs485.print(":");
  rs485.println(measuredSteps);
  
  rs485.flush(); 
  delay(5);
  digitalWrite(RS485_DE, LOW);

  // 8. Finalize
  totalStepsPerRev = measuredSteps;
  homeModule();
}

void moveToChar(char targetChar) {
  int targetIndex = FLAP_CHARS.indexOf(targetChar);
  if (targetIndex == -1) return;
  
  if (currentFlapIndex == -1) {
    homeModule();
  }

  // Calculate where we WANT to be in absolute steps
  // Because totalStepsPerRev is now ~4096, this automatically yields half-steps.
  long targetStepPos = ((long)targetIndex * (long)totalStepsPerRev) / 64;
  
  // Move forward until we hit the target position
  while(currentStepPos != targetStepPos){
    stepBackward(1);
  }

  releaseMotor();
  currentFlapIndex = targetIndex; 
}

// ==========================================
//              MAIN LOOP
// ==========================================

void setup() {
  pinMode(IN1, OUTPUT);
  pinMode(IN2, OUTPUT);
  pinMode(IN3, OUTPUT); 
  pinMode(IN4, OUTPUT);
  pinMode(HALL_PIN, INPUT_PULLUP);
  
  pinMode(RS485_DE, OUTPUT);
  digitalWrite(RS485_DE, LOW); 
  
  rs485.begin(9600);
  homeModule();
}

void loop() {
  while (rs485.available()) {
    char c = rs485.read();
    lastSerialTime = millis();
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

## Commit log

2025-11-13 New KiCad Project for SplitFlapDriverATtiny1616
    [SplitFlapDriver2Board.kicad_pcb, SplitFlapDriver2Board.kicad_sch, SplitFlapDriverATtiny1616.csv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]
2025-11-17 Added SplitFlapBusBoard
    [SplitFlapBusBoard-B_Cu.gbr, SplitFlapBusBoard-B_Mask.gbr, SplitFlapBusBoard-B_Paste.gbr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]
2025-12-05 Version 2 of Hub and Module Board
    Finished and ordered bus board and V2 or Module board (50x)
    [SplitFlapBusBoard-B_Cu.gbr, SplitFlapBusBoard-B_Mask.gbr, SplitFlapBusBoard-B_Paste.gbr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]
2026-02-24 updated firmware
    [SplitFlap12Module.kicad_pcb, SplitFlap12Module.kicad_sch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]
2026-04-25 added wire retainer
    [Wire Retainer.3mf]
2026-04-27 Updated BOM and CPL files to work better in JLCPCB
    [BOM File.xls, SplitFlapDriverATtiny1616V2 BOM.csv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]
2026-04-27 Updated folder name for clarity
    [BOM File.xls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]
2026-04-27 updated BOM and CPL files to work better with JLCPCB
    [BOM File.xls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]
2026-04-27 Added V3 Splitflap PCB
    Contains updated footprint for D1 and R2, which don't require Standard PCB assembly and can use Economic PCBA instead, saving money
    [BOM File.xls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]
2026-04-28 Add 5-module bus board KiCad design
    Alternative bus board layout that connects 5 modules instead of the
    original 3-module design, allowing for fewer bus boards in larger builds.
    [SplitFlapBusBoard-B_Cu.gbl, SplitFlapBusBoard-B_Mask.gbs, SplitFlapBusBoard-B_Paste.gbp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]
2026-04-29 Add animated split-flap live preview to control UI
    Replaces static character grid in the live preview with CSS 3D
    flip animations. Characters roll through the charset to reach
    their target, matching real split-flap hardware behavior.
    Also fixes simulation mode timing so apps pause properly between
    pages when no serial hardware is connected — max_dist is now
    calculated regardless of serial port availability.
    [app.py]
2026-05-04 Added flaps auto generator
    [flap.dxf, flaps.scad, flaps_arial_28.3mf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]
2026-05-04 Added Ypos adjustment and Size adjustement per char
    [flaps.scad]
2026-05-04 added pogo pin details
